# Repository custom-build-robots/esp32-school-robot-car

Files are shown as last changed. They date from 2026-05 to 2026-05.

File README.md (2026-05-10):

# ESP32 School Robot Car - Talente-Tour 2026

A redesigned ESP32-based robot car built for a primary-school robotics project week. PS4/PS5-controller driving, autonomous obstacle avoidance, on-device calibration via OLED menu - open hardware, open code, fully repairable. Built so 8-year-olds can understand every part of it and fix it when something breaks.

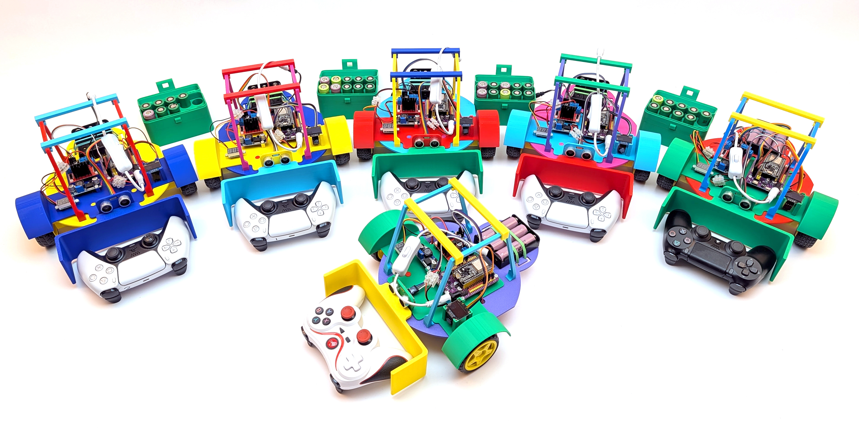
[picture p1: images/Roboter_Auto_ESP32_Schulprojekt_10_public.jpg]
ESP32 school robot car


---

## About this project

In May 2026 I ran a robotics project week as part of the **Talente-Tour 2026** at a primary school near Munich. Six ESP32-powered robot cars were built and programmed by 3rd and 4th graders, who worked through wiring, motor control, and basic programming over the course of the week.

This repository contains everything needed to rebuild the project:

- 🖨️ STL files for the chassis and mechanical parts
- 🔌 A complete hardware list with vendor links
- 💻 ESP32 firmware (Arduino sketch) with PS-controller support, autonomous mode, and on-device calibration

The design philosophy: every component understandable, every part replaceable. No proprietary kits, no glue-the-screws-in. Kids should see what's inside, fix it when it breaks, and modify it when they have a new idea. That's where curiosity starts.

---

## What you'll need

### Hardware

A short overview - see [`HARDWARE.md`](HARDWARE.md) for the full bill of materials with vendor links and prices, and the complete pin-by-pin wiring map.

- 1 × ESP32 development board
- 1 × motor driver (L298N) - the **ENA/ENB pins are jumpered HIGH**, PWM is done on the IN1–IN4 lines instead
- 2 × DC gear motors with matching wheels
- 1 × 0.96″ OLED display (SSD1306, I²C, 128×64) - shows controller status, mode, distance, and the calibration menu
- 1 × HC-SR04 ultrasonic sensor - autonomous obstacle detection
- 1 × PS4 or PS5 controller - wireless driving (paired via Bluepad32)
- 1 × battery holder + 3x18650 batteries (+ 18650 charger)
- 1 x step down converter to adjust the voltage from 11V to 7V for the DC-motors
- jumper wires, screws, USB cable

### Tools

- 3D printer (or a printing service)
- soldering iron (for the header pins, unless your board has them pre-soldered)
- USB cable + a computer with [Arduino IDE](https://www.arduino.cc/en/software) or [PlatformIO](https://platformio.org/)

### 3D-printed parts

All STL files are in [`stl/`](stl/). Recommended print settings:

| Setting | Value |
|---|---|
| Material | PLA |
| Layer height  | 0.2 mm |
| Infill | 20 % |
| Supports | only where indicated in the part-specific README |

---

## Build steps

1. **Print** the chassis and mounts from [`stl/`](stl/)
2. **Solder** header pins to the ESP32 board if needed
3. **Wire** the components according to the pin-by-pin map in [`HARDWARE.md`](HARDWARE.md). Don't forget to **jumper ENA/ENB to HIGH** on the L298N - the firmware does PWM on IN1–IN4, not on the enable pins.
4. **Flash** the firmware from [`firmware/`](firmware/) with the Arduino IDE (or PlatformIO). Required libraries: *Bluepad32*, *Adafruit SSD1306*, *Adafruit GFX*, and *Preferences* (built-in).
5. **Pair** a PS4 or PS5 controller - power on the car, then put the controller into pairing mode (Share + PS button held until the lightbar flashes rapidly). The OLED shows *Ctrl Connected* once it's paired.
6. **Drive, modify, break, repair, repeat.**

---

## Firmware - what it does

The single `.ino` sketch in [`firmware/`](firmware/) gives the car three modes:

### 🎮 Manual mode (default)
Drive the car with a PS4 or PS5 controller. The left stick controls forward/backward and steering. The OLED shows live left/right motor speeds.

### 🤖 Autonomous mode - toggle with Square
The car drives forward at ~60 % speed and uses the HC-SR04 ultrasonic sensor to watch for obstacles. When something is closer than 20 cm, it reverses for ~400 ms, turns in a random direction for ~450 ms, and continues forward. The OLED shows the live distance reading.

### 🛠️ Setup mode - toggle with Options
A menu on the OLED lets you calibrate the **left and right motor trim values** so the car drives straight. No two cheap DC motors run at exactly the same speed; the trim is a per-side multiplier (0–100 %) that scales the faster motor down until both wheels match.

Calibration is stored in **non-volatile storage (NVS)** on the ESP32 - so once a kid finds the right values for *their* car, it remembers them across reboots without ever touching the code or the computer.

### Safety
Motors stop automatically if the controller disconnects, or if no command has been received for 5 seconds.

---

## How this version compares to my other robot car

The same principles, but with a different scope. This version is paired down for a workshop setting:

- **This repo** - PS-controller + HC-SR04 obstacle avoidance + OLED setup menu. Wiring is simple enough that 3rd/4th graders can do it themselves.
- **[esp32-roboter-auto](https://github.com/custom-build-robots/esp32-roboter-auto)** - adds an MPU6050 IMU for precise turn angles and additional driving behaviors. More capable, more wiring, more complex code.

If you're running a workshop or just starting with ESP32 robotics, build the version in this repo first.

---

## License

- **Code** in [`firmware/`](firmware/) - [MIT License](LICENSE)
- **3D models** in [`stl/`](stl/) and **documentation** - [CC BY-SA 4.0](https://creativecommons.org/licenses/by-sa/4.0/)

You're warmly encouraged to use this in your classroom, makerspace, or workshop. If you do, I'd love to hear about it - drop me a line on [LinkedIn](https://linkedin.com/in/ingmar-stapel).

---

## Background

This project builds on design principles from my book ***Roboter-Autos mit dem ESP32*** (Rheinwerk Verlag), simplified for younger learners. The book covers the more advanced setup with autonomous navigation, IMU-based driving, and remote control.

---

## Credits

Built for the **Talente-Tour 2026** by [Ingmar Stapel](https://github.com/custom-build-robots).
Find more at [ai-box.eu](https://ai-box.eu) · [custom-build-robots.com](https://custom-build-robots.com) · [LinkedIn](https://linkedin.com/in/ingmar-stapel)

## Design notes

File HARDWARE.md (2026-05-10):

# Hardware - ESP32 School Robot Car

Complete bill of materials, wiring map, and notes. Prices reflect what I paid in May 2026 in Germany - yours may differ depending on supplier and region.

---

## Bill of materials

| # | Component | Quantity | Approx. price | Vendor |
|---|---|---|---|---|
| 1 | ESP32 dev board (e.g. ESP32-WROOM-32 DevKit V1) | 1 | € 8 | [AliExpress](https://de.aliexpress.com/item/1005006389637966.html) |
| 2 | L298N motor driver module | 1 | € 5 | [AliExpress](https://de.aliexpress.com/item/1005007650595037.html) |
| 3 | DC gear motor with wheel (TT motor 1:48 or similar) | 2 | € 7 | [AliExpress](https://de.aliexpress.com/item/1005006864766296.html) |
| 4 | Caster wheel / front ball roller | 1 | € 3.50 | local shop |
| 5 | 0.96″ OLED display, SSD1306, I²C, 128×64 | 1 | € 2 | [AliExpress](https://de.aliexpress.com/item/1005007084725556.html) |
| 6 | HC-SR04 ultrasonic distance sensor | 1 | € 1.50 | [AliExpress](https://de.aliexpress.com/item/1005007849944952.html) |
| 7 | PS4 or PS5 wireless controller (DualShock 4 / DualSense) | 1 | € X | usually already at home / local shop |
| 8 | Battery holder (3 × 18650) | 1 | € 3 | [AliExpress](https://de.aliexpress.com/item/4000962602731.html) |
| 9 | 18650 cells | 3 | € 14 | [AliExpress](https://de.aliexpress.com/item/1005008704468583.html) |
| 10 | DC adjustable buck converter (step-down to 5 V) | 1 | € 1.50 | [AliExpress](https://de.aliexpress.com/item/1005008183314384.html) |
| 11 | Jumper wires (M-M, M-F, F-F mixed) | 1 set | € 2 | [AliExpress](https://de.aliexpress.com/item/1005007046465880.html) |
| 12 | M3 screws + nuts (10 mm) | ~10 | € 3.50 | local shop |
| 13 | USB cable (Micro-USB or USB-C, depending on board) | 1 | - | usually already at home |

**Total approx. cost per car: € 50 - 60** *(controller often re-used between several cars in a workshop setting)*

---

## Wiring map

The firmware does PWM on the L298N **IN1–IN4** lines, not on ENA/ENB. This means:

> ⚠️ **Bridge ENA and ENB to +5 V (HIGH) on the L298N module.** Most L298N modules ship with a pair of jumpers next to the ENA/ENB headers - leave them in place. If you bought a bare-bones module without jumpers, use two short jumper wires to connect ENA and ENB to the +5 V rail of the module.

### L298N motor driver → ESP32

| L298N pin | ESP32 GPIO | Function |
|---|---|---|
| IN1 | **GPIO 13** | Left motor - direction A (PWM) |
| IN2 | **GPIO 12** | Left motor - direction B (PWM) |
| IN3 | **GPIO 27** | Right motor - direction A (PWM) |
| IN4 | **GPIO 33** | Right motor - direction B (PWM) |
| ENA | (jumpered to +5 V) | Left motor enable - always HIGH |
| ENB | (jumpered to +5 V) | Right motor enable - always HIGH |
| GND | GND | Common ground |
| +12 V (motor power) | — | from 3× 18650 battery pack |

### HC-SR04 ultrasonic sensor → ESP32

| HC-SR04 pin | ESP32 pin | Function |
|---|---|---|
| VCC | 5 V | Power |
| GND | GND | Ground |
| TRIG | **GPIO 5** | Trigger pulse |
| ECHO | **GPIO 18** | Echo (distance reading) |

### OLED display (SSD1306, I²C) → ESP32

| OLED pin | ESP32 pin | Function |
|---|---|---|
| VCC | 3.3 V (or 5 V - check your module) | Power |
| GND | GND | Ground |
| SDA | **GPIO 21** (default I²C SDA) | I²C data |
| SCL | **GPIO 22** (default I²C SCL) | I²C clock |

> The default I²C address used by the firmware is **0x3C**. If your display uses 0x3D, change `SCREEN_ADDRESS` in the sketch.

### Buck converter → ESP32

The 3× 18650 pack delivers ~11.1 V nominal (up to ~12.6 V fully charged) — too high to feed the ESP32 directly. The adjustable buck converter steps that down to 5 V, which is then fed into the ESP32's VIN pin (or the 5 V pin if the board accepts it).

| Buck input | Buck output | Connect to |
|---|---|---|
| IN+ | — | Battery + (also goes to L298N +12 V input) |
| IN− | — | Battery GND (common ground) |
| OUT+ | — | ESP32 **VIN** (5 V) |
| OUT− | — | ESP32 GND |

> Set the output voltage to **5.0 V** with a multimeter *before* connecting the ESP32 — the trim potentiometer on the buck module ships at random factory values and could deliver anything from 1.2 V to nearly the input voltage.

### Controller

The PS4/PS5 controller pairs **wirelessly** via Bluetooth - no wiring needed. The Bluepad32 library on the ESP32 handles pairing and decoding.

To pair: power on the car, then on the controller hold **Share + PS** (PS4) or **Create + PS** (PS5) until the lightbar flashes rapidly. The OLED will show *Ctrl Connected* once paired.

---

## Power notes

- The **3× 18650 battery pack** delivers ~11.1 V nominal (up to ~12.6 V fully charged). This goes to two places:
  - Directly to the L298N +12 V input for the motors
  - Through the buck converter (set to 5 V) to the ESP32 VIN pin
- During programming or bench work, the ESP32 can also be powered via USB. In that case, leave the buck converter disconnected from the ESP32 to avoid back-feeding.
- **Connect all grounds together**: ESP32 GND, L298N GND, buck converter OUT−, battery GND, OLED GND, HC-SR04 GND. Without a common ground reference, the motor driver and sensors won't behave correctly.
- 18650 cells require respectful handling: a charger with cell-balancing, no short-circuiting (especially during wiring), and ideally a battery holder with a built-in protection circuit. For a workshop with kids, consider switching to AA cells in series — slightly less voltage, much safer to fail.

---

## Where to buy

Most components are available at:

- [AliExpress](https://de.aliexpress.com/) — best price, longer shipping
- [Reichelt Elektronik](https://www.reichelt.de/) (DE)
- [AZ-Delivery](https://www.az-delivery.de/) (DE)
- [Eckstein Komponente](https://eckstein-shop.de/) (DE)
- [Berrybase](https://www.berrybase.de/) (DE)
- [Welectron](https://www.welectron.com/) (DE)

Replace this list with whatever you use locally.

---

## Common issues

- **Motors don't move at all** → check that ENA and ENB are jumpered HIGH. Without them, the L298N keeps the motor outputs disabled regardless of the IN1–IN4 signals.
- **Motor only spins in one direction** → check the four direction pins (GPIO 13, 12, 27, 33) and make sure none of them are floating or shorted.
- **Car drives in a curve instead of straight** → that's the calibration use-case. Press *Options* on the controller to enter the setup menu, then adjust *Left Trim* / *Right Trim* until both wheels turn at the same speed. Press *Triangle* to save.
- **ESP32 resets when motors start** → shared power supply collapsing under motor inrush. Either separate the motor power from the ESP32 power, add a 470 µF capacitor across the motor driver's input, or feed the ESP32 from USB during testing.
- **ESP32 won't power on from the battery** → buck converter output not set to 5 V, or buck converter has no input. Disconnect the ESP32, measure the buck output with a multimeter, adjust to 5.0 V with the trim pot, then reconnect.
- **OLED stays blank** → wrong I²C address or swapped SDA/SCL. Try changing `SCREEN_ADDRESS` from `0x3C` to `0x3D` in the sketch. If still blank, swap the SDA and SCL wires.
- **HC-SR04 always reads the same distance** → check the trigger/echo wiring (GPIO 5 / GPIO 18) and make sure the sensor isn't pointing at a soft surface (carpet, foam) - those absorb ultrasound.
- **Controller won't pair** → enable Bluetooth on the controller in pairing mode (Share/Create + PS, until the lightbar flashes *rapidly* - slow flashing means it's just looking for its last paired device). If it still won't pair, uncomment `BP32.forgetBluetoothKeys();` in `setup()`, flash once, then re-comment and re-flash.

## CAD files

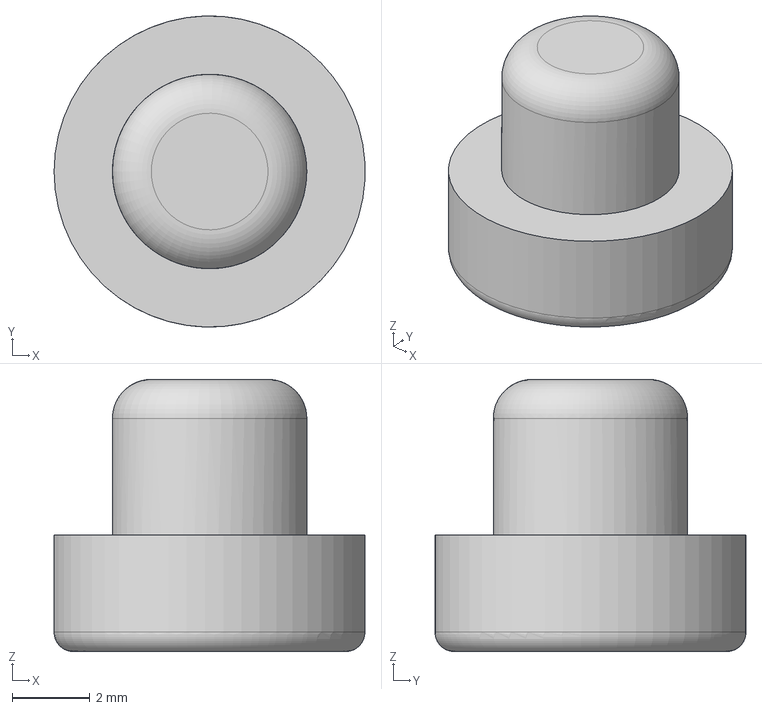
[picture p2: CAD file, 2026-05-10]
stl/mount_pin.step
7.99 x 8.00 x 7.00 mm

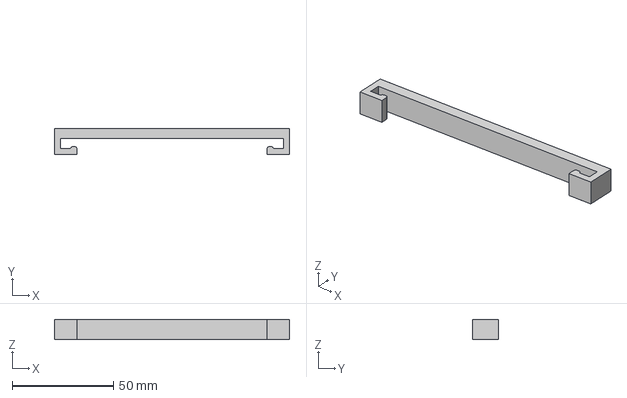
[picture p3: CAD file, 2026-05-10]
stl/stabilizer.step
116.0 x 13.0 x 10.0 mm

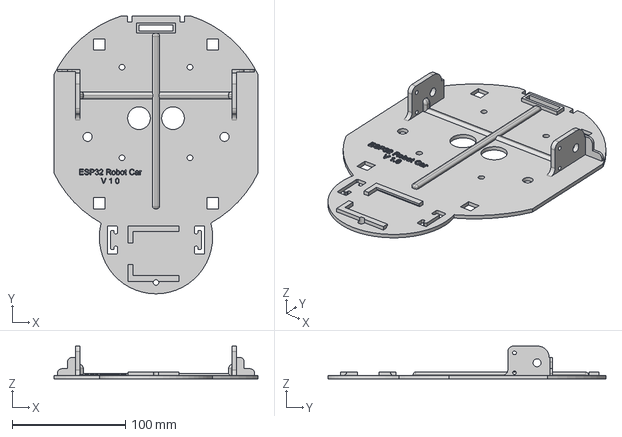
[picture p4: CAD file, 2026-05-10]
stl/TwoWheelRobotV2.step
180.0 x 245.0 x 29.0 mm

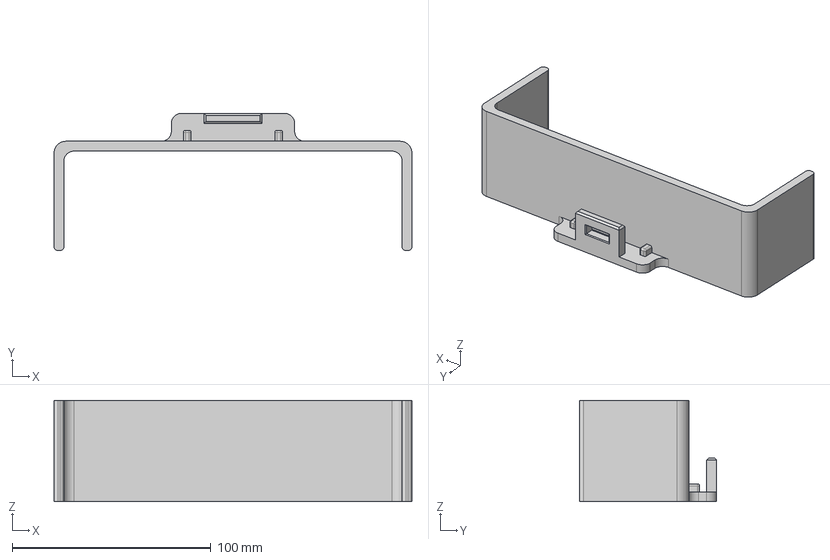
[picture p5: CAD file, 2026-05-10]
stl/Plow.step
180.0 x 69.0 x 51.0 mm

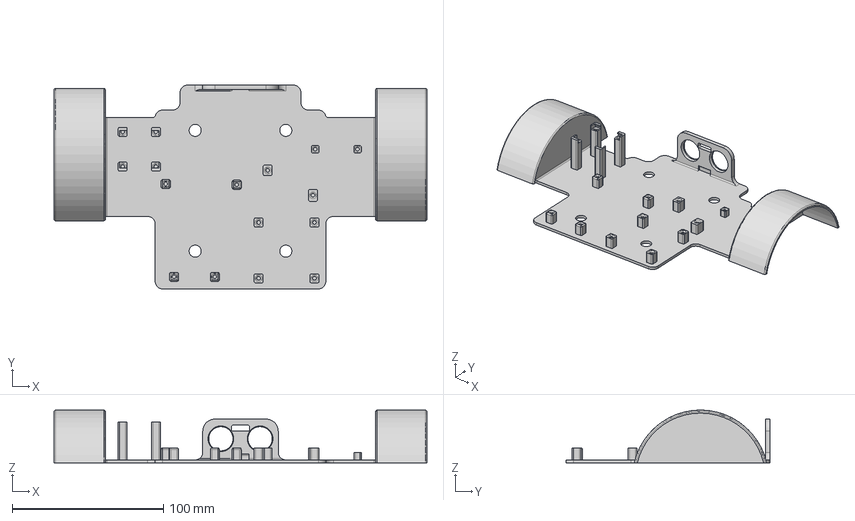
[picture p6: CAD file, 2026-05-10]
stl/Mount-Plate.step
247.0 x 135.0 x 35.0 mm

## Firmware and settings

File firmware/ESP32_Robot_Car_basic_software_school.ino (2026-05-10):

/***************************************************
 * Author: Ingmar Stapel
 * Website: www.custom-build-robots.com
 * Date: 2025-10-30
 * Version: 2.0 
 * Description:
 * This program enables your ESP32-based robot car to be
 * controlled via a PlayStation 4/5 controller using the
 * Bluepad32 library. ENA/ENB on L298N are assumed to be
 * jumpered HIGH. Speed and direction are controlled by
 * PWM signals on IN1, IN2, IN3, IN4 pins.
 ****************************************************/

#include <WiFi.h>
#include <Adafruit_SSD1306.h> // For OLED display
#include <Bluepad32.h>   // Include Bluepad32 library
#include <Preferences.h> // For non-volatile storage (NVS) on ESP32

// ----------------------------
// Adafruit Display Definition (NEU)
// ----------------------------
#define SCREEN_WIDTH 128  // OLED display width, in pixels
#define SCREEN_HEIGHT 64  // OLED display height, in pixels
#define OLED_RESET   -1  // Reset pin # (or -1 if sharing Arduino reset pin)
#define SCREEN_ADDRESS 0x3C ///< I2C-Adresse (häufig 0x3C oder 0x3D)

// Das Display-Objekt mit der Adafruit-Klasse erstellen:
Adafruit_SSD1306 display(SCREEN_WIDTH, SCREEN_HEIGHT, &Wire, OLED_RESET);


// ----------------------------
// GPIO Pin Definitions for L298N Motor Driver INx lines
// ENA and ENB are assumed to be jumpered to HIGH externally.
// ----------------------------
#define MOTOR_LEFT_IN1_GPIO 13  // ESP32 GPIO for L298N IN1
#define MOTOR_LEFT_IN2_GPIO 12  // ESP32 GPIO for L298N IN2
#define MOTOR_RIGHT_IN3_GPIO 27 // ESP32 GPIO for L298N IN3
#define MOTOR_RIGHT_IN4_GPIO 33 // ESP32 GPIO for L298N IN4

// ----------------------------
// ESP32 LEDC PWM Configuration for INx Pins
// ----------------------------
#define MOTOR_LEFT_IN1_PWM_CHANNEL 0
#define MOTOR_LEFT_IN2_PWM_CHANNEL 1
#define MOTOR_RIGHT_IN3_PWM_CHANNEL 2
#define MOTOR_RIGHT_IN4_PWM_CHANNEL 3

#define PWM_MOTOR_FREQUENCY 5000 // Frequency in Hz for motor PWM (e.g., 5000 Hz)
#define PWM_MOTOR_RESOLUTION 8   // Resolution in bits (8-bit = 0-255 speed range)
const int MAX_MOTOR_PWM_VALUE = (1 << PWM_MOTOR_RESOLUTION) - 1; // Max PWM value (255 for 8-bit)

// ----------------------------
// HC-SR04 Ultrasonic Sensor
// ----------------------------
#define TRIG_PIN 5    // ESP32 GPIO connected to HC-SR04 TRIG
#define ECHO_PIN 18   // ESP32 GPIO connected to HC-SR04 ECHO
const unsigned long ECHO_TIMEOUT_US = 25000; // ~4 m max range, prevents long blocking
const int OBSTACLE_DISTANCE_CM = 20;         // Trigger threshold for evasion
const int AUTO_FORWARD_SPEED = 60;           // Forward speed in autonomous mode (%)
const int AUTO_TURN_SPEED = 70;              // Turn speed in autonomous mode (%)
const int AUTO_REVERSE_SPEED = 60;           // Reverse speed in autonomous mode (%)
const unsigned long AUTO_REVERSE_MS = 400;   // Reverse duration before turning
const unsigned long AUTO_TURN_MS = 450;      // Turn duration
const unsigned long DISTANCE_INTERVAL_MS = 80; // How often to ping the sensor

// ----------------------------
// Drive Mode (Manual vs Autonomous vs Setup Menu)
// ----------------------------
enum DriveMode {
  MANUAL_MODE,
  AUTONOMOUS_MODE,
  SETUP_MODE
};
DriveMode currentDriveMode = MANUAL_MODE;

// Autonomous state machine
enum AutoState {
  AUTO_FORWARD,
  AUTO_REVERSE,
  AUTO_TURN
};
AutoState autoState = AUTO_FORWARD;
unsigned long autoStateStartedAt = 0;
int autoTurnDirection = 0; // -1 = left, +1 = right

// Latest measured distance in cm (0 = out of range / no echo)
long lastDistanceCm = 0;

// ----------------------------
// Robot Name
// ----------------------------
const String ROBOT_NAME = "Ingmar's Truck";

// ----------------------------
// Motor Speeds (-100 to 100)
// ----------------------------
int speed_left = 0;
int speed_right = 0;

// ----------------------------
// Command Timeout for Safety
// ----------------------------
unsigned long lastCommandTime = 0;
const unsigned long COMMAND_TIMEOUT = 5000; // 5 seconds

// ----------------------------
// Inversion Option
// ----------------------------
const bool invert_controls = false; // Set to 'true' to invert controls

// ----------------------------
// Direction Multiplier
// ----------------------------
const int direction_multiplier = invert_controls ? -1 : 1;

// ----------------------------
// Motor Speed Trim (Calibration)
// ----------------------------
// If one motor is faster than the other, lower the trim value of the faster
// side until both wheels turn at the same speed. 100 = full speed (no change),
// 95 = run that motor at 95% of the requested speed, and so on.
// These values are loaded from non-volatile memory (NVS) at startup and can
// be edited at runtime via the setup menu (Options button on the controller).
const int MOTOR_TRIM_DEFAULT = 100;
int MOTOR_LEFT_TRIM = 100;   // 0-100 (%) - loaded from NVS in setup()
int MOTOR_RIGHT_TRIM = 100;  // 0-100 (%) - loaded from NVS in setup()

// NVS (non-volatile storage) handle and key names
Preferences prefs;
const char* PREFS_NAMESPACE = "robotcar";
const char* PREFS_KEY_LEFT_TRIM = "left_trim";
const char* PREFS_KEY_RIGHT_TRIM = "right_trim";

// ----------------------------
// Setup Menu State
// ----------------------------
// Menu items: 0 = Left Trim, 1 = Right Trim, 2 = Save & Exit, 3 = Reset Defaults
const int MENU_ITEM_LEFT_TRIM = 0;
const int MENU_ITEM_RIGHT_TRIM = 1;
const int MENU_ITEM_SAVE = 2;
const int MENU_ITEM_RESET = 3;
const int MENU_ITEM_COUNT = 4;
int menuIndex = 0;
unsigned long savedToastUntil = 0; // millis() until which "Saved!" toast is visible

// ----------------------------
// Controller Deadzone
// ----------------------------
const int DEADZONE = 10;
ControllerPtr myControllers[BP32_MAX_GAMEPADS];

void drawSetupMenu(); // forward declaration

void updateDisplayStatus() {
  // In setup mode, the menu drawer takes over the whole screen.
  if (currentDriveMode == SETUP_MODE) {
    drawSetupMenu();
    return;
  }

  // Anpassung für Adafruit: clear() -> clearDisplay(), Text wird mit setCursor und print/println geschrieben
  display.clearDisplay(); 
  display.setCursor(0, 0);

  // Zeile 1: Name des Roboters
  display.print(ROBOT_NAME);

  // Controller Status
  bool controllerConnected = false;
  for (int i = 0; i < BP32_MAX_GAMEPADS; i++) {
    if (myControllers[i] && myControllers[i]->isConnected()) {
        controllerConnected = true;
        break;
    }
  }

  // Zeile 2: Controller Status (Cursor auf Y=10)
  display.setCursor(0, 10);
  if (controllerConnected){
    display.print("Ctrl Connected");
  } else {
    display.print("Ctrl Disconnected");
  }

  // Zeile 3: Drive Mode (Cursor auf Y=20)
  display.setCursor(0, 20);
  if (currentDriveMode == AUTONOMOUS_MODE) {
    display.print("Mode: Auto");
  } else {
    display.print("Mode: Manual");
  }

  // Zeile 4: Distance (nur im Auto-Modus) oder Motorgeschwindigkeiten (Cursor auf Y=30)
  display.setCursor(0, 30);
  if (currentDriveMode == AUTONOMOUS_MODE) {
    if (lastDistanceCm > 0) {
      display.print("Dist: " + String(lastDistanceCm) + " cm");
    } else {
      display.print("Dist: --");
    }
  } else {
    display.print("L:" + String(speed_left) + "% R:" + String(speed_right) + "%");
  }
  
  display.display(); // Zeigt den Puffer auf dem Display an
}

// ----------------------------
// Motor Control Function (PWM on INx pins, ENA/ENB jumpered HIGH)
// ----------------------------
void controlMotorSide(int side_index, int speed_percent) {
    // side_index: 0 for left motor, 1 for right motor
    // speed_percent: -100 (full backward) to 100 (full forward)

    uint8_t in_pin_A_pwm_channel, in_pin_B_pwm_channel;
    int trim_percent;

    if (side_index == 0) { // Left Motor
        in_pin_A_pwm_channel = MOTOR_LEFT_IN1_PWM_CHANNEL; // Connected to MOTOR_LEFT_IN1_GPIO
        in_pin_B_pwm_channel = MOTOR_LEFT_IN2_PWM_CHANNEL; // Connected to MOTOR_LEFT_IN2_GPIO
        trim_percent = MOTOR_LEFT_TRIM;
    } else { // Right Motor
        in_pin_A_pwm_channel = MOTOR_RIGHT_IN3_PWM_CHANNEL; // Connected to MOTOR_RIGHT_IN3_GPIO
        in_pin_B_pwm_channel = MOTOR_RIGHT_IN4_PWM_CHANNEL; // Connected to MOTOR_RIGHT_IN4_GPIO
        trim_percent = MOTOR_RIGHT_TRIM;
    }

    // Apply per-side trim to compensate for unequal motor speeds.
    // The trim only scales DOWN (0-100%), so we cannot exceed full power.
    int trimmed_speed = abs(speed_percent) * constrain(trim_percent, 0, 100) / 100;

    // Calculate PWM duty cycle from trimmed speed percentage
    int pwm_duty = map(trimmed_speed, 0, 100, 0, MAX_MOTOR_PWM_VALUE);
    pwm_duty = constrain(pwm_duty, 0, MAX_MOTOR_PWM_VALUE); // Ensure it's within 0-MAX_MOTOR_PWM_VALUE

    if (speed_percent > 0) { // Forward for this side
        // Pin A gets PWM signal, Pin B is LOW (0% duty cycle)
        ledcWrite(in_pin_A_pwm_channel, pwm_duty);
        ledcWrite(in_pin_B_pwm_channel, 0);
    } else if (speed_percent < 0) { // Backward for this side
        // Pin A is LOW (0% duty cycle), Pin B gets PWM signal
        ledcWrite(in_pin_A_pwm_channel, 0);
        ledcWrite(in_pin_B_pwm_channel, pwm_duty);
    } else { // Stop
        // Both pins LOW (0% duty cycle) - L298N will brake with ENA/ENB HIGH
        ledcWrite(in_pin_A_pwm_channel, 0);
        ledcWrite(in_pin_B_pwm_channel, 0);
    }
}

// ----------------------------
// NVS (Non-Volatile Storage) Helpers
// ----------------------------
void loadTrimsFromNVS() {
  prefs.begin(PREFS_NAMESPACE, true); // read-only
  MOTOR_LEFT_TRIM = prefs.getInt(PREFS_KEY_LEFT_TRIM, MOTOR_TRIM_DEFAULT);
  MOTOR_RIGHT_TRIM = prefs.getInt(PREFS_KEY_RIGHT_TRIM, MOTOR_TRIM_DEFAULT);
  prefs.end();
  // Sanity-clamp in case someone wrote a strange value
  MOTOR_LEFT_TRIM = constrain(MOTOR_LEFT_TRIM, 0, 100);
  MOTOR_RIGHT_TRIM = constrain(MOTOR_RIGHT_TRIM, 0, 100);
  Serial.printf("Loaded trims from NVS: L=%d%% R=%d%%\n",
                MOTOR_LEFT_TRIM, MOTOR_RIGHT_TRIM);
}

void saveTrimsToNVS() {
  prefs.begin(PREFS_NAMESPACE, false); // read-write
  prefs.putInt(PREFS_KEY_LEFT_TRIM, MOTOR_LEFT_TRIM);
  prefs.putInt(PREFS_KEY_RIGHT_TRIM, MOTOR_RIGHT_TRIM);
  prefs.end();
  Serial.printf("Saved trims to NVS: L=%d%% R=%d%%\n",
                MOTOR_LEFT_TRIM, MOTOR_RIGHT_TRIM);
}

void resetTrimsToDefault() {
  MOTOR_LEFT_TRIM = MOTOR_TRIM_DEFAULT;
  MOTOR_RIGHT_TRIM = MOTOR_TRIM_DEFAULT;
  Serial.println("Trims reset to default (100/100). Press Save to persist.");
}

// ----------------------------
// Setup Menu Rendering
// ----------------------------
void drawSetupMenu() {
  display.clearDisplay();
  display.setCursor(0, 0);
  display.print("Setup Menu");

  // Show "Saved!" toast briefly after a save
  if (millis() < savedToastUntil) {
    display.setCursor(70, 0);
    display.print("Saved!");
  }

  // Menu items, each on its own line
  // The cursor character ">" marks the active line.
  const int itemY[MENU_ITEM_COUNT] = {16, 26, 40, 50};

  for (int i = 0; i < MENU_ITEM_COUNT; i++) {
    display.setCursor(0, itemY[i]);
    display.print((i == menuIndex) ? ">" : " ");
    display.setCursor(10, itemY[i]);
    switch (i) {
      case MENU_ITEM_LEFT_TRIM:
        display.print("Left Trim:  ");
        display.print(MOTOR_LEFT_TRIM);
        display.print(" %");
        break;
      case MENU_ITEM_RIGHT_TRIM:
        display.print("Right Trim: ");
        display.print(MOTOR_RIGHT_TRIM);
        display.print(" %");
        break;
      case MENU_ITEM_SAVE:
        display.print("[Save & Exit]");
        break;
      case MENU_ITEM_RESET:
        display.print("[Reset Defaults]");
        break;
    }
  }

  display.display();
}

// ----------------------------
// Setup Menu Enter / Exit
// ----------------------------
void enterSetupMode() {
  // Stop motors immediately - safety first.
  speed_left = 0;
  speed_right = 0;
  controlMotorSide(0, 0);
  controlMotorSide(1, 0);
  currentDriveMode = SETUP_MODE;
  menuIndex = 0;
  savedToastUntil = 0;
  Serial.println("Entered SETUP mode");
  updateDisplayStatus();
}

void exitSetupMode() {
  // Always return to MANUAL after the menu - safer than dropping back into AUTO.
  currentDriveMode = MANUAL_MODE;
  speed_left = 0;
  speed_right = 0;
  controlMotorSide(0, 0);
  controlMotorSide(1, 0);
  Serial.println("Exited SETUP mode -> MANUAL");
  updateDisplayStatus();
}

// ----------------------------
// Setup Menu Input Processing
// ----------------------------
// Buttons:
//   D-Pad Up/Down       -> move cursor between items
//   D-Pad Left/Right    -> change value by 1 (only on numeric items)
//   L1 / R1             -> change value by 5 (only on numeric items)
//   Cross  (a)          -> activate action item (Save / Reset) OR reset value to 100
//   Triangle (y)        -> save & exit (shortcut)
//   Circle (b)          -> cancel: reload values from NVS and exit
//   Options             -> exit without saving (same as Circle but no reload)
void processSetupMenu(ControllerPtr ctl) {
  static bool prevUp = false, prevDown = false, prevLeft = false, prevRight = false;
  static bool prevL1 = false, prevR1 = false;
  static bool prevCross = false, prevTriangle = false, prevCircle = false;

  // D-pad bits in Bluepad32: 0x01=Up, 0x02=Down, 0x04=Right, 0x08=Left
  uint8_t dpad = ctl->dpad();
  bool up    = dpad & 0x01;
  bool down  = dpad & 0x02;
  bool right = dpad & 0x04;
  bool left  = dpad & 0x08;

  bool l1       = ctl->l1();
  bool r1       = ctl->r1();
  bool cross    = ctl->a(); // Cross / X
  bool triangle = ctl->y(); // Triangle
  bool circle   = ctl->b(); // Circle

  // --- Cursor movement (D-pad up/down) ---
  if (up && !prevUp) {
    menuIndex = (menuIndex - 1 + MENU_ITEM_COUNT) % MENU_ITEM_COUNT;
    updateDisplayStatus();
  }
  if (down && !prevDown) {
    menuIndex = (menuIndex + 1) % MENU_ITEM_COUNT;
    updateDisplayStatus();
  }

  // --- Value adjustment (only on numeric items) ---
  bool isNumeric = (menuIndex == MENU_ITEM_LEFT_TRIM || menuIndex == MENU_ITEM_RIGHT_TRIM);
  int delta = 0;
  if (isNumeric) {
    if (right && !prevRight) delta += 1;
    if (left  && !prevLeft)  delta -= 1;
    if (r1    && !prevR1)    delta += 5;
    if (l1    && !prevL1)    delta -= 5;
  }
  if (delta != 0) {
    int* target = (menuIndex == MENU_ITEM_LEFT_TRIM) ? &MOTOR_LEFT_TRIM : &MOTOR_RIGHT_TRIM;
    *target = constrain(*target + delta, 0, 100);
    updateDisplayStatus();
  }

  // --- Cross: activate action items, or reset numeric to 100 ---
  if (cross && !prevCross) {
    if (menuIndex == MENU_ITEM_SAVE) {
      saveTrimsToNVS();
      savedToastUntil = millis() + 800;
      updateDisplayStatus();
      delay(800); // Brief blocking pause so the user actually sees "Saved!"
      exitSetupMode();
      return;
    } else if (menuIndex == MENU_ITEM_RESET) {
      resetTrimsToDefault();
      updateDisplayStatus();
    } else if (isNumeric) {
      // Quick way to zero out a calibration: Cross on a numeric row resets to 100.
      int* target = (menuIndex == MENU_ITEM_LEFT_TRIM) ? &MOTOR_LEFT_TRIM : &MOTOR_RIGHT_TRIM;
      *target = MOTOR_TRIM_DEFAULT;
      updateDisplayStatus();
    }
  }

  // --- Triangle: save & exit shortcut from anywhere ---
  if (triangle && !prevTriangle) {
    saveTrimsToNVS();
    savedToastUntil = millis() + 800;
    updateDisplayStatus();
    delay(800); // Brief blocking pause so the user actually sees "Saved!"
    exitSetupMode();
    return;
  }

  // --- Circle: cancel - reload values from NVS and exit ---
  if (circle && !prevCircle) {
    loadTrimsFromNVS();
    Serial.println("Setup cancelled - values reloaded from NVS");
    exitSetupMode();
    return;
  }

  // Update previous-button state for edge detection
  prevUp = up; prevDown = down; prevLeft = left; prevRight = right;
  prevL1 = l1; prevR1 = r1;
  prevCross = cross; prevTriangle = triangle; prevCircle = circle;

  // Keep safety timeout happy
  lastCommandTime = millis();
}

// ----------------------------
// HC-SR04 Distance Measurement
// Returns distance in cm, or 0 if no echo (out of range / error)
// ----------------------------
long measureDistanceCm() {
  // Send 10us trigger pulse
  digitalWrite(TRIG_PIN, LOW);
  delayMicroseconds(2);
  digitalWrite(TRIG_PIN, HIGH);
  delayMicroseconds(10);
  digitalWrite(TRIG_PIN, LOW);

  // Read echo pulse duration with timeout
  unsigned long duration = pulseIn(ECHO_PIN, HIGH, ECHO_TIMEOUT_US);
  if (duration == 0) {
    return 0; // No echo within timeout
  }
  // Speed of sound ~343 m/s -> 29.1 us per cm round trip / 2 = ~58 us per cm
  return (long)(duration / 58);
}

// ----------------------------
// Autonomous Driving Logic
// Drive forward; on obstacle (<20cm) reverse briefly, then turn random direction.
// If after the turn the obstacle is still close, the next loop iteration will
// trigger another reverse + turn automatically.
// ----------------------------
void runAutonomousDriving() {
  static unsigned long lastDistanceCheck = 0;
  unsigned long now = millis();

  // Measure distance periodically (not every loop, to avoid spamming the sensor)
  if (now - lastDistanceCheck >= DISTANCE_INTERVAL_MS) {
    lastDistanceCheck = now;
    long d = measureDistanceCm();
    lastDistanceCm = d;
    updateDisplayStatus();
  }

  switch (autoState) {
    case AUTO_FORWARD:
      // Drive forward, watch for obstacles. Ignore "0" (no echo = nothing close).
      if (lastDistanceCm > 0 && lastDistanceCm < OBSTACLE_DISTANCE_CM) {
        // Obstacle detected -> start reversing
        autoState = AUTO_REVERSE;
        autoStateStartedAt = now;
        speed_left = -AUTO_REVERSE_SPEED;
        speed_right = -AUTO_REVERSE_SPEED;
        controlMotorSide(0, speed_left);
        controlMotorSide(1, speed_right);
        Serial.println("Auto: obstacle detected, reversing");
      } else {
        // Keep driving forward
        speed_left = AUTO_FORWARD_SPEED;
        speed_right = AUTO_FORWARD_SPEED;
        controlMotorSide(0, speed_left);
        controlMotorSide(1, speed_right);
      }
      break;

    case AUTO_REVERSE:
      if (now - autoStateStartedAt >= AUTO_REVERSE_MS) {
        // Done reversing -> pick a random direction and turn
        autoTurnDirection = (random(0, 2) == 0) ? -1 : 1; // -1 left, +1 right
        autoState = AUTO_TURN;
        autoStateStartedAt = now;
        if (autoTurnDirection < 0) {
          // Turn left in place: left wheels backward, right wheels forward
          speed_left = -AUTO_TURN_SPEED;
          speed_right = AUTO_TURN_SPEED;
          Serial.println("Auto: turning left");
        } else {
          // Turn right in place: left forward, right backward
          speed_left = AUTO_TURN_SPEED;
          speed_right = -AUTO_TURN_SPEED;
          Serial.println("Auto: turning right");
        }
        controlMotorSide(0, speed_left);
        controlMotorSide(1, speed_right);
      }
      break;

    case AUTO_TURN:
      if (now - autoStateStartedAt >= AUTO_TURN_MS) {
        // Done turning -> back to forward; next loop will re-check distance
        autoState = AUTO_FORWARD;
        autoStateStartedAt = now;
        // Don't set speeds here; AUTO_FORWARD case handles it on next call
      }
      break;
  }

  // Keep the safety timeout happy while autonomous driving is active
  lastCommandTime = now;
}

// Stop motors and reset autonomous state machine to a clean starting point
void stopAndResetAuto() {
  speed_left = 0;
  speed_right = 0;
  controlMotorSide(0, 0);
  controlMotorSide(1, 0);
  autoState = AUTO_FORWARD;
  autoStateStartedAt = millis();
}

void onConnectedController(ControllerPtr ctl) {
  bool foundEmptySlot = false;
  for (int i = 0; i < BP32_MAX_GAMEPADS; i++) {
    if (myControllers[i] == nullptr) {
      Serial.printf("Controller connected, index=%d\n", i);
      myControllers[i] = ctl;
      foundEmptySlot = true;
      break;
    }
  }
  if (!foundEmptySlot) {
    Serial.println("Controller connected, but no empty slot found");
  }
  lastCommandTime = millis();
  updateDisplayStatus();
}
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
void loop() {
  bool dataUpdated = BP32.update();
  if (dataUpdated) {
    processControllers();
  }

  // Autonomous driving runs independently of controller updates.
  // It uses the HC-SR04 to drive forward and avoid obstacles.
  if (currentDriveMode == AUTONOMOUS_MODE) {
    runAutonomousDriving();
  }

  // Safety: Stop motors if no commands received recently and a controller was/is active
  bool anyControllerEverActive = false;
   for (int i = 0; i < BP32_MAX_GAMEPADS; i++) {
    if (myControllers[i] != nullptr) { // Check if a slot was ever used or is active
        anyControllerEverActive = true;
        break;
    }
  }
  // Check if a controller is currently connected
  bool controllerCurrentlyConnected = false;
  for (int i = 0; i < BP32_MAX_GAMEPADS; i++) {
      if (myControllers[i] && myControllers[i]->isConnected()){
          controllerCurrentlyConnected = true;
          break;
      }
  }

  if (millis() - lastCommandTime > COMMAND_TIMEOUT) {
    // Only stop if motors are running AND (no controller is connected OR a controller is connected but not sending commands)
    if ((speed_left != 0 || speed_right != 0)) {
      if (!controllerCurrentlyConnected || anyControllerEverActive) { // Timeout applies if a controller was expected or is unresponsive
        speed_left = 0;
        speed_right = 0;
        controlMotorSide(0, speed_left);
        controlMotorSide(1, speed_right);
        Serial.println("Command timeout. Motors stopped.");
        updateDisplayStatus();
      }
    }
  }
  delay(1);
}

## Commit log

2026-05-10 initial upload of all project files
    [Mount-Plate.step, Plow.step, TwoWheelRobotV2.step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]
2026-05-10 Revise hardware documentation with updated components
    Updated bill of materials with actual vendor links and prices, improved clarity on connections and power management for components.
